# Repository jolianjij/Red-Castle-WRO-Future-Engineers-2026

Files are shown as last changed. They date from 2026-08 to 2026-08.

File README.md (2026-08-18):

<p align="center">
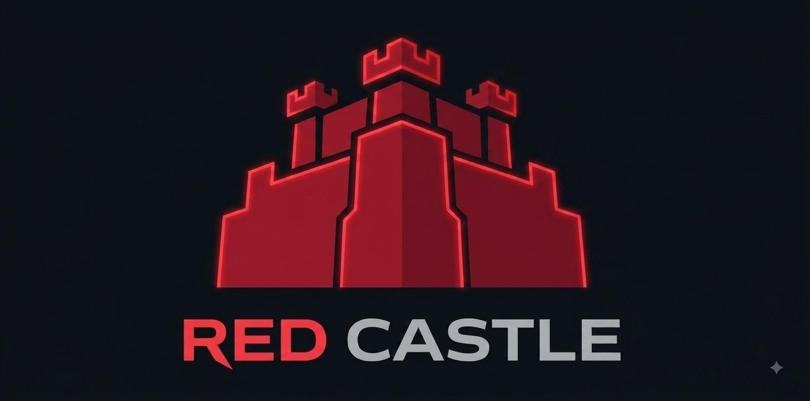
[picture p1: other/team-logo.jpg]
Team The Red Castle
  
</p>

<h1 align="center">Team The Red Castle — WRO 2026 Future Engineers</h1>

An autonomous, self-driving model car for the **World Robot Olympiad 2026,
Future Engineers** category. The mission is the **Open Challenge** (three laps of
a track with a randomised wall layout) and the **Obstacle Challenge** (three laps
avoiding red and green traffic signs, then parking in a marked bay), driven by a
**single camera as its only sensor** — no LiDAR, no ultrasonic rangefinders, no
wheel encoders, no IMU. The Open Challenge runs the full mission; the Obstacle
Challenge currently completes the driving and sign-passing portion, with the
parking manoeuvre still being wired in — see [§10](#10-results--future-work).

> **Design thesis:** everything the car needs to know — where the walls are, which
> way to lap, where the traffic signs are, and where the parking lot is — is
> visible. A well-tuned camera plus disciplined image processing can do the whole
> job, so we spent our engineering effort on making that one sensor reliable
> rather than fusing many.

---

## Table of contents
1. [The challenge](#1-the-challenge)
2. [Vehicle at a glance](#2-vehicle-at-a-glance)
3. [Mobility management](#3-mobility-management)
4. [Power & sense management](#4-power--sense-management)
5. [Software & obstacle management](#5-software--obstacle-management)
   · [flowchart](#51b-control-loop-flowchart) · [direction & laps](#51b-2-direction-and-lap-counting)
   · [obstacle priority](#51c-obstacle-challenge-priority)
   · [subsystem map](#56-how-the-subsystems-fit-together)
   · [testing & metrics](#57-testing-tuning-and-validation)
   · [risks](#58-risks-and-mitigations)
6. [Calibration workflow](#6-calibration-workflow)
7. [Build & run](#7-build--run)
8. [Bill of materials & cost](#8-bill-of-materials--cost)
9. [Engineering process](#9-engineering-process)
10. [Results & future work](#10-results--future-work)
11. [Repository map](#11-repository-map)
12. [Team](#12-team)

---

## 1. The challenge

WRO Future Engineers asks for a fully autonomous vehicle that drives a track
bounded by walls:

- **Open Challenge** — 3 laps; the inner walls are placed at random distances each
  round, so the path width changes and cannot be hard-coded.
- **Obstacle Challenge** — 3 laps with red/green **traffic signs** on the track:
  the car must pass **red signs on their right** and **green signs on their left**,
  then finish by **parking** in the magenta parking lot.

Scoring rewards completing laps without touching walls or signs, correct sign
handling, a clean park, and — importantly — **thorough engineering documentation**
(this repository).

## 2. Vehicle at a glance

| Subsystem | Choice |
|---|---|
| **Compute** | Raspberry Pi 4 Model B, **2 GB RAM** (Raspberry Pi OS *Bookworm*, 64-bit) |
| **Sensor** | **OV5647 Wide-angle** camera (5 MP, ~120° FOV, **fixed focus**) — sole sensor |
| **Steering** | **Ackermann** front steering, MG90S servo on **GPIO13**, **±35° max** |
| **Drive** | **N20 gear motor** (12 V, 200 rpm) → **25:20 gear pair** → **differential** on the rear axle |
| **Driver** | **L9110S** H-bridge on **GPIO24 / GPIO23** |
| **Control** | One push button on **GPIO19** — press to start, press again to stop |
| **Power** | 3 × 18650 (series) → motor driver directly; separate buck converter → Pi; common ground |
| **Chassis** | 3D printed in **PLA+ Silk Silver** on a **Bambu Lab A1**, designed in **Fusion 360** |
| **Software** | Python 3, OpenCV, Picamera2 |

_Vehicle photos: [`v-photos/`](v-photos) · driving video: [`video/video.md`](video/video.md)_

### Specifications

| Property | Value |
|---|---|
| Drive motor | N20 gear motor, 12 V, 200 rpm |
| Transmission | 25:20 spur pair (1.25:1) → differential, rear axle |
| Steering | Ackermann, ±35° max |
| Camera height / tilt | 12.5 cm above the mat / ~15° down |
| Mass | **407 g** |
| Theoretical top speed | **≈ 0.39 m/s** (39 cm/s), no-load — see §3.4 |
| Wheel diameter | **4.7 cm** |
| Wheelbase (front axle ↔ rear axle) | **9.4 cm** |
| Track (rear wheel centre ↔ centre) | **8.5 cm** |
| Overall dimensions (L × W × H) | **14.2 × 9.3 × 15 cm** |
| Print material | PLA+ Silk Silver |
| Printer / CAD | Bambu Lab A1 / Fusion 360 |

## 3. Mobility management

### 3.1 Chassis
A custom chassis designed in **Fusion 360** and 3D printed in **PLA+ Silk Silver**
on a **Bambu Lab A1** (source CAD, STLs and sliced plates in [`models/`](models)).
It carries the Pi, battery, motor driver, drive motor, steering servo and the
camera mast. Design priorities: low and central mass, a rigid camera mast, and
easy access to the wiring.

<p align="center">
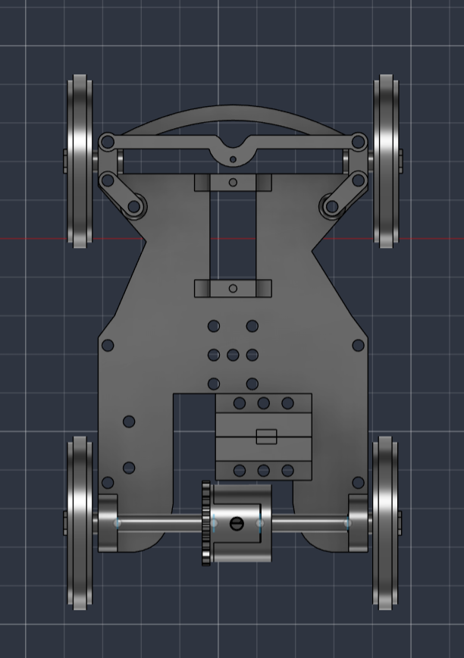
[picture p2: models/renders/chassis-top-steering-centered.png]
Chassis, steering centred
  
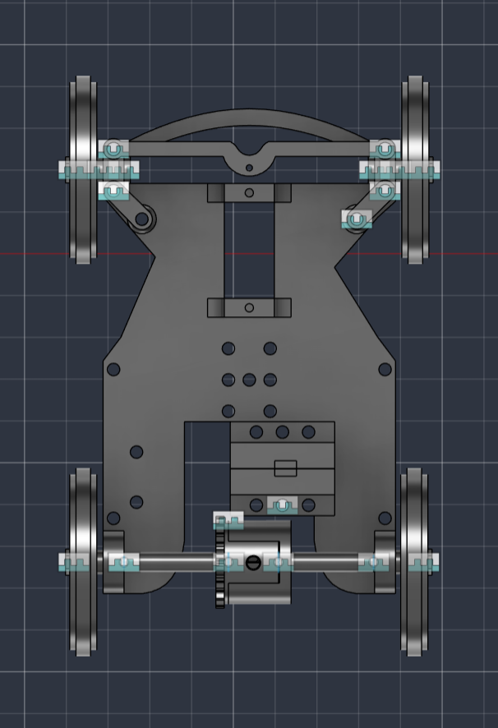
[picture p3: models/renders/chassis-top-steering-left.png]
Chassis, steering turned
  
</p>

### 3.2 Steering — Ackermann
Front-wheel **Ackermann steering** driven by a single MG90S servo (GPIO13, a
hardware-PWM pin for a smooth, low-jitter signal). Metal gears over the plain
SG90 hold up better to the full-lock steering the scripted turns and wall-
emergency escapes both drive it to repeatedly. The servo drives a central
bell-crank and tie-rod to both steering knuckles, so the **inner wheel turns more
sharply than the outer one** through a corner — each wheel follows its own turning
radius instead of fighting the other.

**Maximum steering angle: ±35°**, the mechanical limit of the linkage. `STEER_MAX`
in [`src/config.py`](src/config.py) caps *every* steering command — wall-following,
obstacle-passing and emergency turns — from one constant.

### 3.3 Drivetrain — differential
An **N20 gear motor (12 V, 200 rpm)** drives the rear axle through a **25:20 gear
pair (1.25:1 reduction)** into a **differential**.

> **Engineering decision — why a differential mattered.** Our first drivetrain
> used a *solid* rear axle, forcing both driven wheels to the same speed. In a
> corner the outer wheel must travel further than the inner one, so with a solid
> axle they *scrub* — losing traction, pushing the car wide, and sometimes
> stalling it mid-turn. We worked around it by cutting the steering limit down to
> roughly **8°**, which kept traction but left the car unable to corner properly.
> Fitting a **differential** removed the constraint at its source: the wheels can
> now rotate at different speeds, so we run the **full ±35°** of the linkage and
> corner tightly without scrub. See [`Documentation.pdf`](Documentation.pdf) §5.

The motor is driven by an **L9110S** dual H-bridge:

| L9110S | Connection |
|---|---|
| `A-IA` | GPIO24 — PWM here = **forward** |
| `A-IB` | GPIO23 — PWM here = **reverse** |
| `VCC` | Battery + (motor supply) |
| `GND` | Common ground |
| MOTOR-A | Drive motor |

Speed = PWM duty on one input, the other held LOW. The L9110S was chosen for its
tiny size and simple two-pin-per-motor interface.

> **Safety rule in software.** `motor()` **never switches forward↔reverse
> directly**: it first coasts to a stop and waits (`STOP_FLIP_DELAY`) before
> driving the other way. A hard reversal while the motor is still spinning dumps
> the motor's back-EMF onto the supply and can destroy the Pi's regulator — we
> learned this the hard way (see the journal).

### 3.4 Torque and speed reasoning

The drivetrain was sized around one question: **how fast can the car go while the
vision loop still has time to react?**

**Speed chain**

```
N20 motor          200 rpm  @ 12 V (no load)
  ↓ 25:20 spur pair (1.25:1 reduction)
Differential axle  200 / 1.25 = 160 rpm
  ↓ wheel circumference
Ground speed       v = π · D · 160 / 60   (D = wheel diameter in m)
```

With our **measured wheel diameter (4.7 cm)**:

```
v = π × 0.047 m × 160 rpm / 60 = 0.394 m/s  ≈ 39 cm/s  (no-load ceiling)
```

That is the motor's theoretical maximum with nothing slowing it down. The real
running speed is lower once tyre friction, the differential, and the car's 407 g
mass are accounted for — the 100% cruise setting in software is what actually
runs during a lap, with `cruise_speed()` easing it back further under steering.

**Why gear down at all?** The 1.25:1 reduction trades ~20 % of top speed for
~25 % more torque at the axle (torque scales with the reduction, speed inversely).
That matters because:

- The car must **pull away from rest** repeatedly and climb over the mat seam
  without stalling. Our earlier drivetrain *did* stall — see the journal.
- The L9110S wastes ~1.5–1.8 V, so the motor never sees the full pack voltage;
  extra mechanical advantage compensates for the lost electrical headroom.
- More torque means the controller can use **lower duty cycles** for the same
  motion, which keeps current (and driver heating) down.

**Why not faster?** The vision loop runs at a finite frame rate. At ~0.5 m/s the
car covers ~2–3 cm per frame, so a wall or sign is seen many frames before it
matters. Doubling the speed would halve that reaction margin without improving the
score — the challenge rewards *completing* laps cleanly, not raw speed. The
software also **reduces speed in proportion to steering effort**
(`cruise_speed()`), so the car is fastest exactly where it is safest: on straights.

**Mechanical stability.** At **407 g** total mass on a **14.2 × 9.3 × 15 cm**
footprint, the car is light and compact enough that keeping mass low and central
matters for cornering grip — the battery and Pi sit over the **9.4 cm wheelbase**,
between the front and rear axles, rather than overhanging either end. The **8.5 cm**
rear track keeps the wheelbase-to-track ratio close to 1:1, which is a stable
proportion for cornering without tipping risk. The camera sits on a rigid mast
rather than a flexible arm, and the Ackermann geometry means the wheels roll
rather than scrub through a corner. A vibrating camera would corrupt the wall
measurements, so mast rigidity is a control requirement, not a cosmetic one.

## 4. Power & sense management

### 4.1 Power topology
Early on, the Pi rebooted every time the motor drew current. The fix defines our
power design and is now standard on the car:

```
3 x 18650 (series) ─┬──────────────────────► L9110S VCC   (motor power, direct)
   via rocker switch└─► DC-DC buck (5 V) ───► Raspberry Pi 5V
Battery − ──── common ground ── L9110S GND ── Pi GND
```

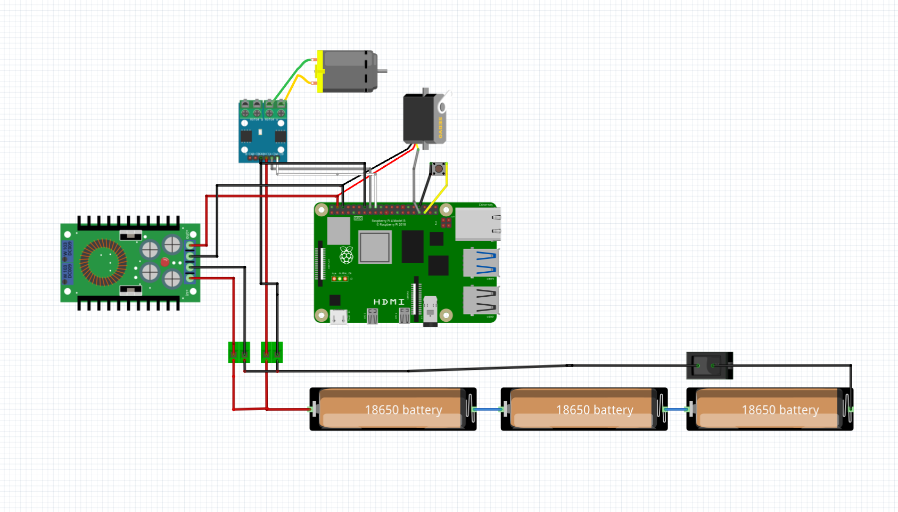
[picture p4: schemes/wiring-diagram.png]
Wiring diagram


_Full wiring notes: [`schemes/`](schemes)._

1. **Separate rails** — the motor draws straight from the battery; the Pi has its
   **own regulator**. Motor current spikes never pass through the Pi's supply.
2. **Common ground** — Pi, driver and battery negatives are tied together so the
   GPIO control signals share a reference. (Without it, the only link between Pi
   and driver is the signal wire, and motor return current back-feeds the GPIO pin
   — which browns out or damages the Pi.)

### 4.2 Power budget

Sizing the pack: what draws current, how much, and for how long.

| Load | Rail | Typical | Peak | Notes |
|---|---|---|---|---|
| Raspberry Pi 4 (2 GB) | 5 V (buck) | ~0.6 A | ~1.2 A | rises while the vision loop runs |
| OV5647 camera | 3.3 V via CSI | ~0.25 A | ~0.25 A | powered by the Pi, no separate rail |
| MG90S steering servo | 5 V (buck) | ~0.15 A | ~0.7 A | peak only during a fast steering step |
| N20 drive motor | 12 V (battery) | ~0.15 A | ~0.8 A | limited by the L9110S's ~0.8 A ceiling |
| L9110S quiescent | 12 V | ~0.01 A | — | negligible |

**Reasoning**

- **Pi rail:** 0.6 + 0.25 + 0.15 ≈ **1.0 A typical**, ~2.1 A worst case if the Pi
  peaks while the servo slams. The buck converter is specified at **≥ 3 A**, giving
  roughly 40 % headroom over the worst case — deliberately generous, because
  under-sizing this rail is what caused our early brownouts.
- **Motor rail:** the motor is fed **straight from the pack**, so its spikes never
  touch the Pi's rail. This separation is the single most important power decision
  on the car (§4.1).
- **Runtime:** 3 × 18650 in series keeps the *capacity* of one cell (~2500–3000 mAh)
  while tripling voltage. The 12 V side draws ~0.15 A average; the 5 V side draws
  ~1.0 A but the buck converter steps *down*, so the current it pulls from the 11 V
  pack is roughly `1.0 A × 5 V / 11 V / 0.85 ≈ 0.53 A`. Total ≈ **0.7 A**, giving on
  the order of **3–4 hours** of running — far beyond the few minutes a run needs.
  Practice sessions, not runtime, drain the pack.
- **Failure points considered:** motor stall (bounded by the L9110S current limit),
  reverse back-EMF (handled in software by a forced coast before any direction
  change), pack sag under load (why the rails are separated), and the fact that a
  freshly charged 12.6 V pack sits marginally above the L9110S's 12 V rating — a
  known watch-item logged in [`schemes/`](schemes).

_These are datasheet/typical figures used for sizing; a clamp-meter measurement of
the real draw is a pending task._

### 4.3 Sensing — the camera
The camera is the entire perception system, so most of our tuning went here.

**Sensor choice.** We began with a Raspberry Pi Camera Module 3 Wide (IMX708) but
switched to an **OV5647 wide-angle module**. The Module 3's large sensor and
autofocus lens gave a *shallow depth of field*: focus it on the mat and distant
traffic signs blurred, which desaturated their colour and made them undetectable.
The OV5647 is a **small-sensor, fixed-focus** module, so its depth of field covers
the whole track — near mat and far walls are sharp simultaneously — and there is
no autofocus to hunt mid-run. Losing autofocus cost us nothing; a ground robot
never needs to refocus.

**Connection.** The camera uses the Pi's dedicated **CSI port** via a flat ribbon
cable — it takes no GPIO pin and needs no separate power, which is why it does not
appear on the wiring diagram.

**Mount — justified by field geometry.** **12.5 cm above the mat**, tilted **~15°
downward**, centred laterally and facing straight ahead on a rigid mast. It is
physically mounted **upside-down**, so frames are rotated 180° in software.

Each number follows from the field itself:

| Choice | Driven by | Reasoning |
|---|---|---|
| **Height 12.5 cm** | walls are **10 cm** tall | The lens must sit **above the wall line** so the camera looks *down onto* the mat and sees the wall **base** — the white-mat/black-wall edge, the highest-contrast feature available. Below 10 cm the walls would fill the frame as a flat black band with no distance information. |
| **Not much higher** | depth resolution vs clutter | Raising the camera improves distance precision by only ~30 % at long range while showing more of the room *over* the walls. Not worth the extra clutter and mast flex — analysed in the journal. |
| **Tilt ~15° down** | track width & look-ahead | Enough downward angle to keep the mat and both wall bases in the lower frame, while still seeing far enough ahead to detect a corner and a traffic sign before reaching them. |
| **Centred, zero yaw** | left/right symmetry | Wall following compares the **left half against the right half** of the image. Any lateral offset or twist becomes a permanent steering bias that no amount of tuning removes. |
| **120° wide lens** | corridor width | A narrow lens cannot see **both** side walls at once in the corridor; the wide lens keeps both walls and the corner lines in a single frame. |
| **Rigid mast** | measurement noise | Vibration blurs the wall edge and injects noise straight into the steering loop, so mast stiffness is a control requirement, not cosmetic. |

**Calibration method.** Colour thresholds are field-calibrated, never hard-coded:
`tools/camera_tune.py` first fixes the *image* (exposure, gain, white balance,
saturation) and writes `camera_settings.json`; `tools/color_tuner.py` then samples
each real object on the real mat and writes `colors.json`. Steering centre is
calibrated by `tools/servo_center.py` into `servo_center.txt`. The car reads all
three files at start-up, so re-calibrating never means editing code.

**Locked settings** (`src/camera.py`), chosen from on-field capture tests:

| Setting | Value | Why |
|---|---|---|
| Sensor mode | 1296×972 (full ~120° FOV) → scaled to 640×480 | keep the wide FOV; cropped modes would lose it |
| Orientation | `hflip + vflip` (180°) | camera mounted upside-down |
| Focus | **fixed** (no AF hardware) | deep depth of field — sharp from the near mat to the far wall |
| Exposure | fixed (~9–12 ms) | freeze motion — auto-exposure ran ~60 ms and smeared when moving |
| White balance | locked `ColourGains` | keep HSV thresholds stable as the car turns toward/away from lights |
| Saturation | raised (~1.4) | separates red / orange / green / magenta in HSV, free in the ISP |

> **Why camera-only?** A single well-configured camera sees walls, the orange/blue
> corner lines, the coloured signs and the parking lot — everything the rules
> reference. Removing LiDAR/ultrasonic cut cost, weight, wiring and failure modes,
> and let us focus on making the vision robust (locked exposure/AWB, fixed focus,
> field-tuned HSV).

## 5. Software & obstacle management

All control software is in [`src/`](src). Four core modules import each other and
run together; the calibration and test utilities live in [`src/tools/`](src/tools).

```
src/robot.py               shared library — pins, servo()/motor(), HSV masks, wall/line/pillar analysis
src/camera.py              locked camera setup
src/open_challenge.py      Open Challenge main
src/obstacle_challenge.py  Obstacle Challenge main
```

### 5.1 Vision pipeline
`capture → 180° flip → crop the mat ROI → resize 320×160 → median blur → HSV`.
HSV is computed with `cv2.COLOR_BGR2HSV` everywhere so thresholds transfer between
the tuner and the challenge code. Six colours are thresholded from `colors.json`
(produced by `tools/color_tuner.py`, values shown are our measured ranges):

| Colour | Used for | HSV range (H, S, V) |
|---|---|---|
| black | walls | a **two-tier** test, not a single threshold — see below |
| blue | corner line (CCW) | H 96–135, S 60–255, V 70–200 |
| orange | corner line (CW) | H 2–13, S 72–170, V 70–255 |
| green | traffic sign | H 30–95, S 140–255, V 30–170 |
| red | traffic sign | H 170–5 (wraps), S 150–255, V 60–255 |
| magenta | parking lot | H 130–145, S 177–255, V 93–255 |

**Wall detection is a two-tier test, not a brightness threshold.** A single
"value < 62" test also lit up the blue/orange lines and the mat's printed dotted
markings, because they're dark too — and unevenly between the two frame halves,
which injected a steering bias. A real wall is either **very dark** (V < 32,
regardless of saturation) **or dark and desaturated** (V < 62 **and** S < 90).
The two-case test matters because HSV saturation is numerically unstable at very
low brightness — a black wall can report S > 200 from sensor noise, so testing
saturation alone throws real walls away. The magenta parking-lot pixels are also
counted as wall until the parking phase, since we have no parking-specific
calibration yet.

**Where colours are searched matters as much as their range.** Corner lines are
painted on the mat, so they can only appear in the image's lower portion —
searching the *whole* frame let bluish wall/background pixels near the top
trigger a false blue-line reading on ~40% of frames in one test run. Line search
is now restricted to the bottom 45% of the region of interest.

### 5.1b Control-loop flowchart

Every frame runs the same **look → think → act** loop. Each challenge program
owns its own `decide()` — one pure function holding the whole priority ladder,
with no hardware or camera in it, so the entire brain can be unit-tested on a
laptop (`tools/test_logic.py`).

```mermaid
flowchart TD
    A([Start]) --> B[Capture frame<br/>OV5647, 180 deg flip]
    B --> C[Crop mat ROI, resize 320x160,<br/>median blur, convert to HSV]
    C --> D[Measure left/right wall density,<br/>front density, line fractions]
    D --> E[LapTracker.update:<br/>direction + lap counting]
    E --> F{Either wall past<br/>WALL_EMERGENCY?}
    F -- yes --> G[Proportional escape,<br/>full lock if BOTH walls close]
    F -- no --> H{Scripted turn<br/>active?}
    H -- yes --> I[Hold full lock in the<br/>locked direction]
    H -- no --> J{Front wall very close<br/>and direction known?}
    J -- yes --> K[Trigger the turn anyway<br/>-- geometry backup]
    J -- no --> L[Outer-wall PD control:<br/>hold target distance to ONE wall]
    G --> M[Clamp to STEER_MAX, set servo]
    I --> M
    K --> M
    L --> M
    M --> N[Scale speed down with<br/>steering effort, set motor]
    N --> O[Log the frame to CSV]
    O --> P{Lap count satisfied<br/>and timer expired?}
    P -- no --> B
    P -- yes --> Q([Stop: motor 0, servo centre])
```

### 5.1b-2 Direction and lap counting

Direction is decided **once**, from the corner lines, and is never re-decided —
that is what stops the car flipping from clockwise to counter-clockwise mid-run.

- **The first time a corner line is seen**, whichever colour has the larger pixel
  count in that frame sets the direction: orange bigger → clockwise, blue bigger
  → counter-clockwise. From that point `direction` is fixed for the whole run.
- **Wall geometry is a second opinion, not a vote.** At the same moment, if the
  two frame halves differ by at least `GEOM_DIR_MIN_DIFF` (0.08), we check
  whether geometry agrees. If it does, the log records a confirmation; if not, a
  disagreement is logged but the line's decision stands. This threshold exists
  because, measured head-on to a corner, the two halves read 0.26 vs 0.22 — a
  0.04 difference that is noise, not information, and it once produced a
  confident but wrong guess against a correct line reading.
- **Lap counting only runs once direction is known**, and only from a **line
  crossing**: a colour going from present to absent (a falling edge) counts one
  *quadrant* — but only if the line lockout timer has expired. That timer
  restarts on every count, so one physical crossing is read exactly once even if
  the mask flickers.
- **What this means honestly:** if the corner lines are never detected for an
  entire run, direction never locks and laps never count — wall-following still
  works (it defaults to the clockwise convention), but the run won't finish
  itself. `FORCE_DIRECTION` in `config.py` is the manual override for this case:
  set it before a run if lighting or colour tuning is in doubt.
- **Front-wall geometry has one job at this level**: if the car is already
  driving in a known direction and a wall gets very close ahead
  (`FRONT_TURN_BACKUP`) without a scripted turn already running, it triggers the
  turn anyway so a missed line can't drive the car into the wall. This backup
  protects the car, not the lap count — it does not add a quadrant.

Every run's log ends with a summary line, e.g. `direction=CCW via bigger line
(blue 0.061) | corners=11 (geom 0, line 11) | disagreements=0`, so a run can be
read back and checked without re-watching it.

### 5.1c Obstacle Challenge priority

Steering is decided by a strict **priority ladder** in one pure function,
`decide()`. Exactly one branch answers each frame, ordered so a lower-priority
behaviour can never override a safety-critical one.

```mermaid
flowchart TD
    A[Every frame] --> P{Still in the<br/>parking lot?}
    P -- yes --> P1[Measure magenta each side,<br/>drive out, LOCK the direction]
    P -- no --> K{Corner just counted, and the<br/>last sign pushed us inward?}
    K -- yes --> K1[Fixed 30 deg kick<br/>out of the corner]
    K -- no --> W{Wall past<br/>WALL_EMERGENCY?}
    K1 --> W
    W -- yes --> W1[Ramped escape,<br/>floored by the controller]
    W -- no --> S{Sign visible?}
    S -- yes --> S1[Place it: red to our right,<br/>green to our left]
    S -- no, seen in the last 3 s --> H[Hold, then run straight]
    S -- no --> L[Outer-wall PD lane keeping]
```

| # | Behaviour | Why it sits at this level |
|---|---|---|
| **0** | **Parking exit** | Runs once, before the car moves. Inside the lot the magenta walls are close *on purpose*, so it must outrank the wall escape or the escape would fight the way out. |
| **1** | **Corner kick** | A committed open-loop manoeuvre. It outranks the wall escape because it is *deliberately* turning toward a wall — except when a wall closes from the **opposite** side, which cancels it. |
| **2** | **Wall escape** | Touching a wall ends the run. Ramps 50 %→100 % across the danger band and is **floored by the normal controller**, because an escape weaker than the controller it replaces steers *into* the wall (measured: −0.8° produced where the follower wanted −17°). |
| **3** | **Sign steering** | Passing signs correctly scores points, so it outranks plain lane keeping. |
| **4** | **Sign hold** | Detection flickers frame to frame (measured: one sign's area went 61 → 851 → 0 → 1060 over four frames). The hold is in **seconds**, not frames, so it does not change with frame rate. |
| **5** | **Lane keeping** | The same outer-wall PD proven in the Open Challenge, used when nothing else applies. |

**Why lane keeping exists at all.** A design that steers only toward signs and
relies on the wall override firing "often enough" between them does not hold on
our optics: measured mid-corridor readings of 0.112/0.129 against a 0.213
override threshold, meaning the car would drive dead straight for 44 % of a test
run with nothing correcting it. Falling back to the proven outer-wall controller
closes that gap.

### 5.1d Leaving the parking lot — and how it fixes the direction

The car starts inside the magenta parking lot. Whichever side is more blocked is
the side it *cannot* leave by, so the free side is both the way out **and** the
direction the lap will run. One measurement, taken before the car has moved,
answers both questions:

| what the camera sees | way out | lap direction |
|---|---|---|
| more magenta on the **left** | leave **right** | **CW** (+1) |
| more magenta on the **right** | leave **left** | **CCW** (−1) |

Because `+1` already means "steer right" everywhere in the code, the exit
steering is simply `direction × angle` — one number answers both.

The measurement is averaged over 8 frames while the car is **stationary**: the
only moment in the run with no motion blur, and worth spending. If neither side
shows enough magenta the car declines to guess and leaves the direction to the
corner lines, because a wrong direction locked at frame one would ruin the whole
run.

> **We do not add the black wall to this measurement.** A synthetic test first
> suggested the two signals were anti-correlated — the magenta wall occludes the
> black wall behind it. **Measured on the real track they agree**: in the lot,
> magenta read L 0.716 / R 0.449 while the wall read L 0.174 / R 0.093, both
> naming the same side. The anti-correlation was an artifact of the test image,
> where blank background counted as wall.
>
> It stays off for a simpler reason: magenta alone already gives a clear margin,
> and it is the *direct* signal — the parking lot is defined by magenta, whereas
> black is every wall on the track. `PARK_USE_WALL` enables it if a venue ever
> makes magenta's margin marginal.

### 5.2 Open Challenge algorithm

1. **Direction** is set once, from the first corner line seen (§5.1b-2), and
   never changes for the rest of the run.
2. **Between corners**, a PD controller holds a fixed distance to the **outer**
   wall only — the left wall clockwise, the right wall counter-clockwise. The
   *inner* wall is never referenced, because its distance from the track centre
   is randomised each round; the outer wall is the one constant.
3. **At a corner**, crossing the driving-direction's line fires a **scripted
   turn**: full steering lock in the known direction, held for at least 0.35 s
   and at most 1.1 s, ending as soon as the way ahead reads clear rather than on
   a fixed clock. A fixed-duration turn was tried first and over-rotated into the
   inner wall in both directions (measured: inner-wall density climbed
   0.126 → 0.195 → 0.278 during one such turn) — ending on "the corner is
   clear" instead of "a timer expired" fixed that.
4. **A wall emergency always wins**, in any state: if either wall crosses
   `WALL_EMERGENCY`, the controller escapes proportionally to how close it is,
   and if *both* walls are close at once (jammed facing a corner) it latches a
   single escape direction instead of alternating between the two — an earlier
   version let left and right readings cross each other frame to frame, which
   flipped the command between +20° and −20° and made the car directionless
   exactly when it needed decisive action.
5. **Stop** once 11 quadrants are counted *and* the lap timer has expired, so the
   car finishes driving through the last straight instead of halting on the line.

### 5.3 Obstacle Challenge algorithm

1. **If a sign is visible**, steer to place it on the correct side: the target
   column is computed from the sign's position and how close it is, sliding
   further toward the frame edge as the sign nears, so the car curves around it
   rather than swerving late.
2. **If a sign was visible recently but isn't this frame**, hold the last
   command for a few frames instead of reacting to the drop-out — this is what
   keeps a single flickered detection from aborting a pass halfway through.
3. **If no sign is in view or remembered**, fall back to the same outer-wall
   lane-keeping law as the Open Challenge, so the car doesn't simply coast
   straight between signs.
4. **A wall override sits above all three** — the same emergency threshold as
   the Open Challenge, and it also does the job of turning the car through each
   corner, since the Obstacle Challenge has no separate scripted-turn sequencer.

### 5.4 Speed
Base speed is `CRUISE`; `cruise_speed()` **eases off in proportion to steering
effort**, so the car runs fast on straights and slows automatically for corners.

## 5.6 How the subsystems fit together

```mermaid
flowchart LR
    subgraph POWER[Power]
        BAT[3 x 18650<br/>~11.1 V] --> SW[Switch]
        SW --> BUCK[Buck 5 V]
        SW --> DRV[L9110S]
    end
    subgraph SENSE[Sensing]
        CAM[OV5647 wide<br/>fixed focus] -- CSI --> PI
    end
    subgraph THINK[Compute]
        PI[Raspberry Pi 4<br/>robot.py loop]
    end
    subgraph ACT[Actuation]
        SRV[MG90S servo<br/>Ackermann]
        MOT[N20 motor] --> GEAR[25:20] --> DIFF[Differential] --> WHL[Rear wheels]
    end
    BUCK --> PI
    BUCK --> SRV
    DRV --> MOT
    PI -- GPIO13 PWM --> SRV
    PI -- GPIO24/23 PWM --> DRV
    CFG[(colors.json<br/>servo_center.txt<br/>camera_settings.json)] --> PI
    PI --> LOG[(CSV run log)]
```

**Interactions that actually constrained the design**

| Interaction | Constraint it created |
|---|---|
| Motor ↔ Pi share one battery | Rails **must** be separated and grounds tied, or the Pi browns out (§4.1). |
| Drivetrain ↔ steering software | A solid axle forced the steering limit down to ~8°; the differential raised the mechanical limit to 35°. We run the software limit at **20°** for stability at full speed — mechanics set the ceiling, tuning sets where under it we actually drive. |
| Camera mount ↔ control loop | Mount height/tilt/rigidity determine what the controller can even measure; a loose mast is a control failure. |
| Lighting ↔ colour thresholds | Auto-exposure made HSV drift, so exposure and white balance are **locked** and colours re-tuned on the real mat. |
| Camera choice ↔ obstacle detection | Shallow depth of field blurred distant signs, so the sensor was swapped for a fixed-focus module. |
| Frame rate ↔ top speed | Speed is capped so the car moves only a few cm per frame, preserving reaction margin. |

## 5.7 Testing, tuning and validation

**How we test.** Each subsystem has a dedicated tool so faults are isolated rather
than guessed at (all in [`src/tools/`](src/tools)):

| Stage | Tool | What it proves |
|---|---|---|
| Wiring | `driver_on.py`, `test.py` | servo sweeps, motor turns both ways, camera captures |
| Motor limits | `motor_speed_steps.py` | steps 100 → 50 % to find the stall point |
| Motor path | `motor_debug.py` | separates a PWM fault from a power fault |
| Camera image | `camera_tune.py` | exposure/gain/saturation, with a live `mean_sat / blown% / dark%` read-out |
| Colour | `color_tuner.py` | each colour verified against its real object, mask checked for speckle |
| Wall vs shadow | `shadow_check.py` | splits dark pixels into a "tall solid run" (a real wall) vs a shallow spread (likely shadow), so a misreading can be diagnosed on the spot |
| Outer-wall control | `outer_test.py` | moves the car by hand and prints what the controller *would* steer, before it is ever trusted at speed |
| Decision logic | `test_logic.py` | the whole brain on a laptop, no Pi — 50+ assertions over `decide()`, the lap tracker and the corner kick |
| Full decision chain | `dryrun.py` | runs both challenges' `decide()` against the live camera, **motor never touched** |
| Start/stop button | `button_test.py` | confirms the button's wiring and that one press produces exactly one event |
| Full run | `open_challenge.py` / `obstacle_challenge.py` | logs every frame to `logs/*.csv` |

**Metrics we record.** Every run writes a CSV row per frame — timestamp, cycle,
direction, quadrant, in-corner flag, left/right wall, blue/orange line fractions,
steering and speed — plus a summary line (quadrants, cycles, elapsed time,
ms/cycle). That log is how we tune: after a bad run we read *why* the car did what
it did instead of guessing.

| Metric | Why it matters |
|---|---|
| ms per cycle | loop rate — sets how far the car travels blind between frames |
| quadrants counted vs. real corners | validates lap counting |
| seconds between corners | catches a corner counted twice or missed |
| left/right wall balance on a straight | proves the camera is centred and the controller is not biased |
| steering saturation (% of frames at `STEER_MAX`) | shows whether gains are too high |

**Tuning process.** Change one constant in [`src/config.py`](src/config.py) → run →
read the log → keep or revert. Because every threshold lives in one file and all
calibration lives in JSON/text files, a tuning change never risks breaking code.

## 5.8 Risks and mitigations

| Risk | Impact | Mitigation |
|---|---|---|
| Motor current spike browns out the Pi | run ends, SD card can corrupt | separate rails, own buck converter, common ground (§4.1) |
| Forward↔reverse slam destroys the regulator | hardware loss | `motor()` forces a coast + settle before any direction change |
| Lighting changes at the venue | colour masks fail | exposure/AWB locked; colours re-tuned on site in minutes via `color_tuner.py` |
| Corner line never detected all run | direction never locks, laps never count | **known limitation** — wall-following still runs (default clockwise), but the run won't self-finish; `FORCE_DIRECTION` in config is the manual override if colour is in doubt at the venue |
| One corner line missed mid-run | that quadrant undercounts | the front-wall geometry backup still forces the physical turn, so the car doesn't crash — only the count is affected, not the turn |
| Direction mis-detected | car laps the wrong way | decided once from the larger of the two line readings, cross-checked against wall geometry, then locked for the whole run |
| Camera knocked out of alignment | permanent steering bias | rigid mast; left/right balance check before every run |
| Mat markings or shadows read as a wall | false obstacle / steering bias | two-tier wall test (very dark, or dark **and** desaturated) rejects coloured lines and most shadow; `shadow_check.py` diagnoses any that still gets through — this was a live issue at two corners in field testing and is still being tightened |
| Car stuck against a wall | run wasted | `MAX_CORNER_CYCLES` and `MAX_RUNTIME_S` force an exit/stop |
| Fresh pack exceeds L9110S 12 V rating | driver overheats | monitored; noted in [`schemes/`](schemes) |
| Algorithm underperforms on the day | lost points | every tunable sits in one block at the top of the challenge file — speed, lane distance in cm, sign gains — so behaviour is retuned at the venue without touching logic |
| Car must be stopped mid-run | damage, or a wasted attempt | one button on GPIO19 starts the run and stops it at any moment; the loop polls it every frame |

## 6. Calibration workflow

Every calibration writes a file that `robot.py` loads at start-up, so the
competition code itself never has to be edited to retune the car.

| Tool | Produces | Purpose |
|---|---|---|
| `tools/tune_colors.py` | `camera_settings.json`, `colors.json` | **the venue tool.** Re-locks exposure/white balance, then every colour, then checks all pairs for overlap. Headless — runs over plain SSH. |
| `tools/tune_walls.py --detector` | `wall_settings.json` | what counts as a **wall** in this light |
| `tools/tune_walls.py` | printed constants | density ↔ centimetres, fitted through parked measurements |
| `tools/servo_center.py` | `servo_center.txt` | trim so 0° = straight (current value **−9°**) |
| `tools/button_test.py` | — | confirm the start/stop button's wiring |
| `tools/color_tuner.py` | `colors.json` | the older interactive GUI tuner (needs a screen) |

**The order matters and cannot be swapped**, because each step is measured
through the previous one: **colours → wall detector → distances**. Re-locking
the white balance after tuning colours silently invalidates them; changing the
wall detector changes every density measured against it.

**The wall detector does not use a colour range.** It uses `WALL_V_HARD`,
`WALL_V_SOFT` and `WALL_S_MAX` — three brightness/saturation cuts. Tuning the
`black` colour therefore does *not* retune the walls, which is exactly the sort
of thing that looks like it worked and has not. `tune_walls.py --detector`
samples the wall, the mat and a line and places the thresholds in the gap
between them; if wall and mat overlap in brightness it refuses to write
anything, because no threshold can separate them in that light.

Full competition-day procedure: [`other/venue-setup.md`](other/venue-setup.md).

## 7. Build & run

**Raspberry Pi OS Bookworm** — Picamera2/OpenCV come from `apt`, **not** pip
(a pip numpy shadows the apt one and breaks Picamera2):

```bash
sudo apt install -y python3-picamera2 python3-libcamera python3-opencv python3-rpi-lgpio python3-venv
```

### Running a challenge

```bash
cd ~/wro2026 && source .venv/bin/activate && python open_challenge.py
```

Then **press the button**. Nothing moves before that — the program arms and
waits. Pressing it again stops the run at any moment; it is also the emergency
stop, and the loop polls it every frame.

### At the start line, with no laptop

```bash
./autostart.sh on
```

The program then launches at every power-on, so the start-line procedure becomes
**power the car, press the button**. This is safe precisely *because* the
program waits for the button: booting into it only arms the car. When a run
finishes the service restarts it, re-arming it for the next press. Which program
runs is one line at the top of `run.sh`.

### Before every deploy

```bash
python tools/test_logic.py    # the whole brain, on a laptop, no Pi needed
python tools/dryrun.py        # both challenges, live camera, motor untouched
```

## 8. Bill of materials & cost

Full component list: [`other/bill-of-materials.md`](other/bill-of-materials.md).
Wiring: [`schemes/`](schemes). **Total build cost: ≈ $120** (electronics, printed
parts, fasteners and battery combined).

## 9. Engineering process

The interesting part of this project was making one camera and a cheap drivetrain
reliable. The full design log — sensor choice, the power-brownout debugging, the
motor stall, the no-differential steering decision, and the camera focus/exposure
tuning — is in the Evolution section of **[`Documentation.pdf`](Documentation.pdf)**.

## 10. Results & future work

**Open Challenge — complete.** The vehicle drives the full three laps and stops
correctly **in both directions (clockwise and counter-clockwise)** with stable
control, holding its line along the straights and taking the corners without
contact. Both driving directions are demonstrated in the submitted video.

The decisive fix was not in the controller but in the perception: the wall
detector had been counting the blue and orange corner lines, and the mat's printed
markings, as walls — see [`Documentation.pdf`](Documentation.pdf) §5. Once
corrected, every distance constant was re-measured, so the control setpoints are
now real distances (driving line 40 cm from the outer wall, emergency at 18 cm,
full steering lock at 20 cm of error) rather than tuned pixel fractions.

**Obstacle Challenge — driving and sign-passing complete, parking not yet wired
in.** Sign passing (red on the right, green on the left) and lane keeping between
signs both run, with a short memory that holds a manoeuvre through a flickered
detection instead of aborting it. The magenta parking lot is currently treated
purely as a wall to avoid; detecting the gate and executing the approach is
built into `config.py` as reserved constants but not yet connected into the main
loop. The other known open issue is **shadow at two of the four corners**
occasionally being read as part of the wall, which biases the density measurement
there; `tools/shadow_check.py` was built specifically to separate a genuine wall
(a tall, solid dark run) from a shadow (broad and shallow) and diagnose it in the
field, and the wall test is being tightened against it.

**Future work.**
- Wire the parking manoeuvre into the Obstacle Challenge's main loop.
- Close out the corner-shadow misreading identified above.
- Upgrade wall-following from a pure PD law to a heading + offset controller, so
  the car holds a straighter line rather than correcting after it has already
  drifted.
- Track a sign's position across frames rather than per-frame, to smooth the
  approach further than the current short-memory hold already does.

## 11. Repository map

```
README.md                 # this engineering document
Documentation.pdf          # printable engineering journal (hard-copy submission)
CHECKLIST.md               # submission checklist
src/                       # control software (core + tools/)
models/                    # 3D-printable parts + source CAD
schemes/                   # wiring / electromechanical diagrams
t-photos/                  # team photos
v-photos/                  # vehicle photos (6 angles)
video/                     # link to the driving demonstration
other/                     # BOM, rulebook, misc
```

## 12. Team

<p align="center">
  Red Castle
  &nbsp;&nbsp;&nbsp;
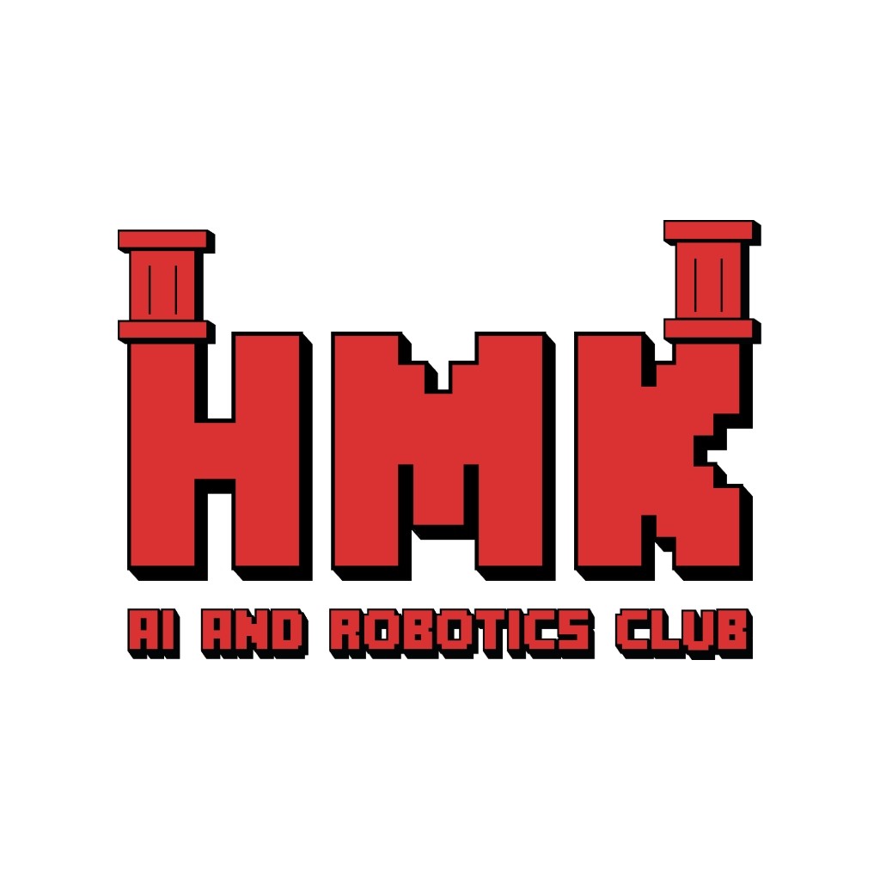
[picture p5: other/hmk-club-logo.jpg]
HMK AI and Robotics Club
  
</p>

**Team The Red Castle** — HMK AI and Robotics Club.

<table>
  <tr>
    <td align="center" width="25%">
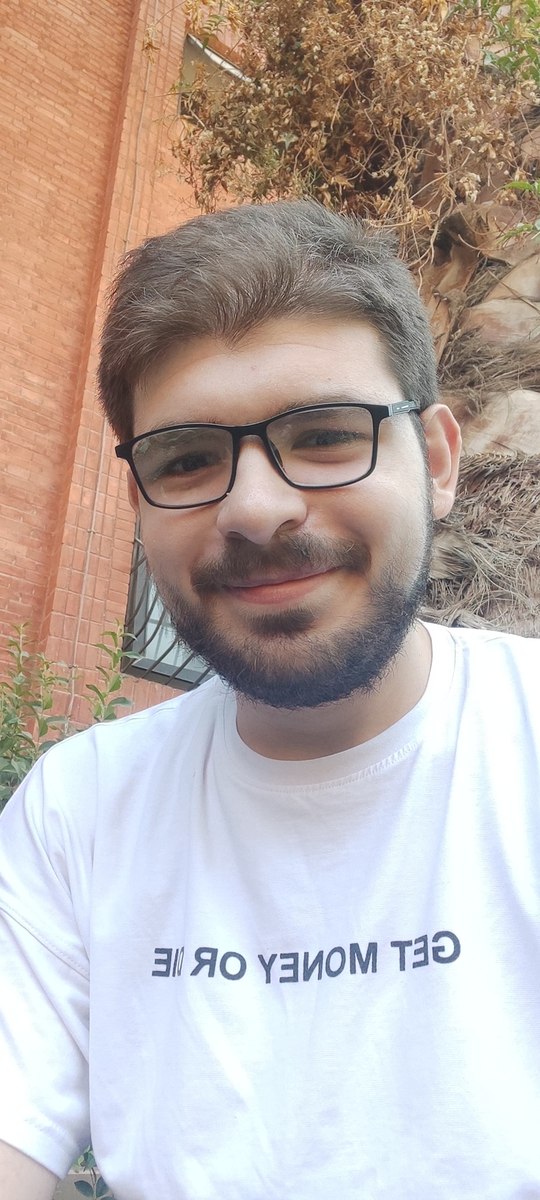
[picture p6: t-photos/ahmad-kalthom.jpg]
Ahmad Kalthom
      <br>
      <b>Ahmad Kalthom</b><br>
      <sub>Coach</sub>
    </td>
    <td align="center" width="25%">
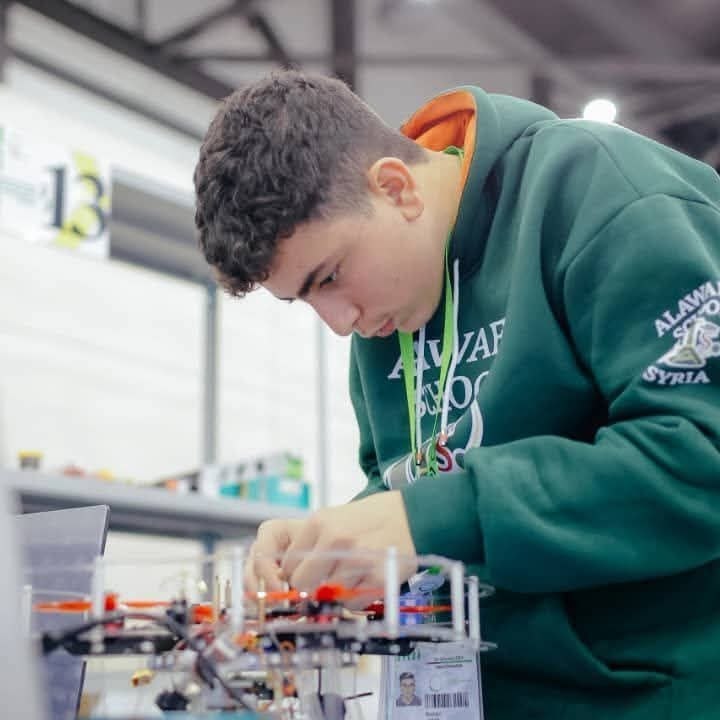
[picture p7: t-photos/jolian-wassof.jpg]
Jolian Wassof
      <br>
      <b>Jolian Wassof</b><br>
      <sub>Team member</sub>
    </td>
    <td align="center" width="25%">
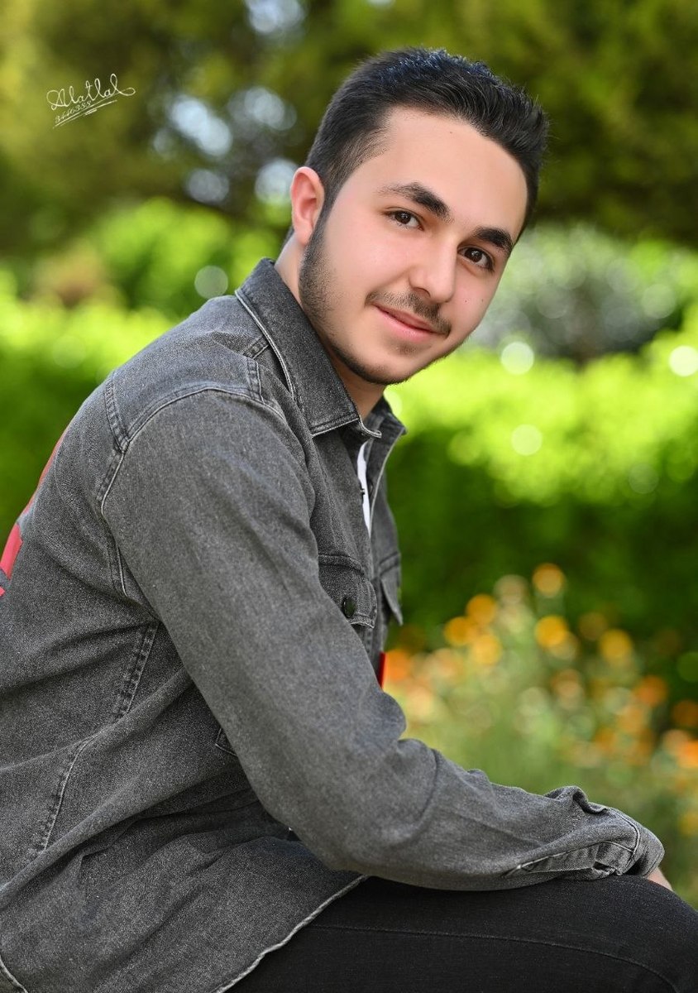
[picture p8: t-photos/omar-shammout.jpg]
Omar Shammout
      <br>
      <b>Omar Shammout</b><br>
      <sub>Team member</sub>
    </td>
    <td align="center" width="25%">
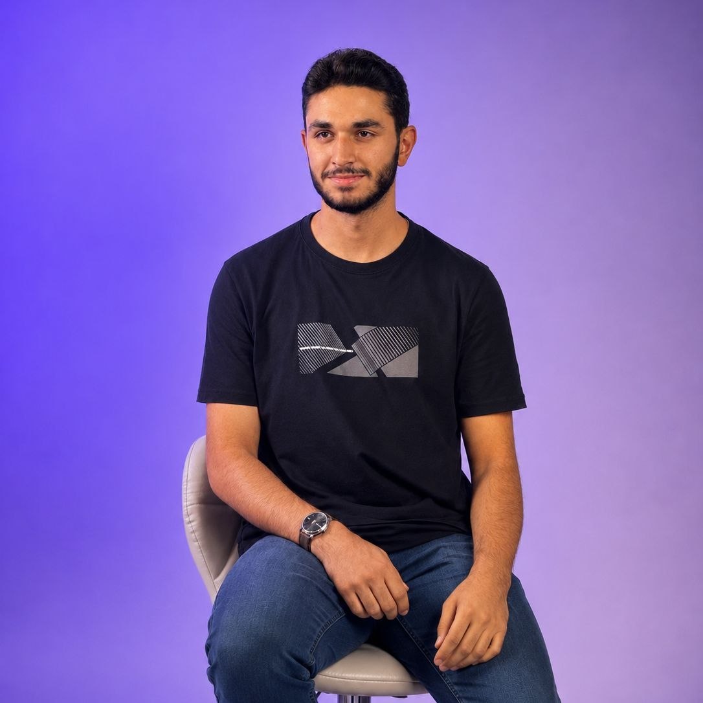
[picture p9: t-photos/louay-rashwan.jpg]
Louay Rashwan
      <br>
      <b>Louay Rashwan</b><br>
      <sub>Team member</sub>
    </td>
  </tr>
</table>

### Ahmad Kalthom — Coach
> Computer and Automation Engineering student at Damascus University, interested
> in embedded systems and automatic control. Works on applied projects to design
> effective automation solutions within a competitive environment.

**Education:** Computer and Automation Engineering, Damascus University
**Focus areas:** Embedded Systems, Automatic Control
📧 ahmedkalthom977@gmail.com

### Jolian Wassof — Team member
> Student at Al-Awael School, interested in artificial intelligence, robotics,
> drones, and engineering. Has competed in the Pacific Olympiad in AI, the Syrian
> Olympiad in AI, and the World Robot Olympiad, as well as mobile robotics and
> unmanned aerial systems competitions. Has built several AI-based robots and
> drones, and conducts research in AI.

**Education:** Al-Awael School
**Focus areas:** Artificial Intelligence, Robotics, Drones
📧 joleanwassof@gmail.com

### Omar Shammout — Team member
> IT Engineering student at Damascus University, interested in robotics,
> artificial intelligence, programming, and electronics. Participates in
> technical activities and projects to develop skills in designing and building
> innovative solutions within a competitive environment.

**Education:** IT Engineering, Damascus University
**Focus areas:** Robotics, Artificial Intelligence, Programming, Electronics
📧 omarhamze.shammout@gmail.com

### Louay Rashwan — Team member
> Computer and Automation Engineering student at Damascus University, interested
> in robotics, artificial intelligence, and electronics. Participates in
> technical activities and projects to develop skills in designing and building
> innovative solutions within a competitive environment.

**Education:** Computer and Automation Engineering, Damascus University
**Focus areas:** Robotics, Artificial Intelligence, Electronics
📧 rashwanlouay@gmail.com

Built on a Raspberry Pi 4 with an OV5647 wide-angle camera.

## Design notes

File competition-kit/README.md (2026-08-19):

# Competition kit — WRO 2026 Future Engineers

Team The Red Castle · HMK AI and Robotics Club

Everything needed at the venue, in one folder. The layout **mirrors the Pi**,
so the whole folder can be copied to `~/wro2026` and every tool will find the
programs next to it.

```
competition-kit/
├── open_challenge.py                  the open challenge program
├── obstacle_challenge.py              the obstacle challenge program
├── WRO2026-Control-and-Tunables.pdf   every tunable + the control equations
├── TUNING-STRATEGY.md                 what to do at the venue, in order
├── build_pdf.py                       regenerates the PDF from the code
└── tools/
    ├── mask_debug.py     every mask on one picture       START HERE
    ├── wall_calib.py     wall-following targets
    ├── line_audit.py     line thresholds
    ├── sign_calib.py     pillar distance and pixel counts
    ├── park_calib.py     parking walls and the exit direction
    ├── color_count.py    pixel count for ANY new colour   surprise challenge
    └── servo_jitter.py   proves whether the servo shake is the pulse
```

## Which program is which

**`open_challenge.py`** — wall following on density, lines only count laps.
Finishes 3 s after the 12th quadrant.

**`obstacle_challenge.py`** — the version you asked for: their original green
release and per-direction line counting, the blocking corner kick on orange,
the `v >= 70` parking-wall filter — **with the parking algorithm removed**.
After the 12th quadrant it finishes like the open challenge instead of hunting
for the parking bay. `PARKING_ENABLED = True` brings the whole thing back.

Both keep every value you tuned on the Pi.

## Running

```bash
cd ~/wro2026 && source .venv/bin/activate && python open_challenge.py
```

Press the button to start. Press it again to stop — it is the emergency stop.

Every run writes its own timestamped CSV under `logs/`, so a bad run is never
overwritten by the next one. Both programs print every tunable at startup, so
the log says what produced it.

## The tools

All of them import the challenge program itself, so they use its real capture,
crop, colour tests and wall mask. They cannot quietly disagree with the car —
which is how two genuine bugs were caught.

| tool | run it when |
|---|---|
| `mask_debug.py` | first thing at the venue, and any time something looks wrong |
| `wall_calib.py cw` / `ccw` | before every session — lighting moves the densities |
| `line_audit.py blue` / `orange` | if a lap is miscounted or a line is missed |
| `sign_calib.py` | if a pillar is ignored or hit |
| `park_calib.py` | before an obstacle run, in the start box |
| `color_count.py` | surprise challenge, or any new colour |
| `servo_jitter.py` | if the steering buzzes |

None of them move the car. The motor is never touched.

## Before the first run of the day

1. `systemctl is-active pigpiod` — must say `active`. Without it the servo
   falls back to software PWM and buzzes. The program warns loudly if so.
2. `python tools/mask_debug.py` — look at the picture.
3. `python tools/wall_calib.py cw` and `ccw` — re-measure the targets.

## Regenerating the PDF

Every number in the PDF is parsed out of the two programs at build time, so it
can never drift from the code. After changing a tunable:

```bash
python build_pdf.py
```

Run it on the laptop — it never imports `picamera2`.

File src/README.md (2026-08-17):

# src — the code

## The whole thing in five files

```
open_challenge.py      RUN THIS   three laps, empty track
obstacle_challenge.py  RUN THIS   three laps, red/green traffic signs
robot.py               the car: hardware, camera, seeing, control
config.py              every tunable number shared by both challenges
camera.py              camera setup (locked exposure and white balance)
```

Only the first two are programs you run. Everything else is support.

```
colors.json            the tuned HSV ranges (made by tools/color_tuner.py)
camera_settings.json   the locked white balance (made by tools/camera_tune.py)
servo_center.txt       steering centre trim (made by tools/servo_center.py)
tools/                 helpers - see below
archive/               superseded experiments, kept for the journal
```

---

## Every challenge program has the same three parts

This is the important bit. Open either program and you will find, in order:

### 1. TUNABLES
A single block at the top. **Nothing outside it needs editing.** Speed,
direction, how far from the wall to drive, how hard to react to a sign.

### 2. `decide()`
The brain. **One frame in, one steering decision out.** It is a *priority
ladder* — a list of `if` statements from most urgent to least, where exactly
one branch answers:

```python
def decide(view, laps, outer, turner):
    if a wall is too close:      return escape        # 1. EMERGENCY
    if we are cornering:         return turn          # 2. TURN
    return follow the outer wall                      # 3. LANE
```

`decide()` touches no hardware and no camera — it is pure arithmetic on
numbers. That is deliberate: it means the whole brain can be tested on a
laptop, with no Pi, in under a second.

### 3. `main()`
The loop. Always the same four steps:

```python
button.wait_for_start()          # nothing moves until you press it
while True:
    view = R.look(cam)           # LOOK   one frame, everything measured
    d = decide(view, ...)        # THINK  one decision
    R.servo(d.steer)             # ACT
    R.motor(speed)
    if button.stop_pressed(): break   # RECORD / FINISH
```

---

## How to write the surprise challenge

The surprise challenge is announced at the venue. You will not have time to
invent anything, so don't — **copy a program and rewrite one function.**

**1. Copy the closest existing program.**
```bash
cp open_challenge.py surprise_challenge.py
```
Start from `open_challenge.py` if the task is about driving and walls; from
`obstacle_challenge.py` if it involves coloured objects.

**2. Change the TUNABLES block** to whatever the new task needs.

**3. Rewrite `decide()`.** This is the only real work. Write the ladder in
plain words first, most urgent at the top, then translate each line:

> *"Don't hit anything. Otherwise, if I can see the thing, go to it.
> Otherwise, keep driving down the middle."*

```python
def decide(view, laps, outer, turner):
    escape = R.wall_emergency(view.left, view.right, outer, laps.direction)
    if escape is not None:
        return Decision(escape, "emergency")
    ...your new rule here...
    return Decision(R.apply_bias(outer.steer(view.left, view.right,
                                             laps.direction)), "lane")
```

**4. Leave `main()` almost alone.** Change the log filename and the printed
header. The button, the loop, the logging and the safety timeout all work
already.

**5. Test before you drive it.**
```bash
python tools/test_logic.py     # on the laptop, no Pi needed
python tools/dryrun.py         # on the Pi, camera on, motor never touched
```

### What you can call inside `decide()`

Everything the car can sense arrives in one `view` object:

| field | meaning |
|---|---|
| `view.left`, `view.right` | how much of that half of the picture is wall. **Bigger = closer.** |
| `view.front` | the same, straight ahead. High means a corner. |
| `view.blue`, `view.orange` | how much corner line is visible |
| `view.hsv` | the raw HSV image, for your own colour work |
| `view.proc` | the colour image, for saving annotated frames |

Useful helpers in `robot.py`:

| call | what it does |
|---|---|
| `R.wall_emergency(left, right, outer, direction)` | escape steering, or `None` if safe |
| `R.mask(hsv, "red")` | pixels matching a tuned colour |
| `R.apply_bias(steer)` | adds the straight-line drift trim (lane keeping only) |
| `R.cruise_speed(base, steer)` | slows down in proportion to steering |
| `R.OuterWallFollower(target=…)` | PD control on the distance to one wall |
| `R.CornerKick(...)` | a fixed, time-boxed, open-loop turn |

**Sign conventions, everywhere:** steering `0` = straight, **+ = right**,
**− = left**. Direction `+1` = clockwise, `−1` = counter-clockwise.

---

## The button (GPIO 19)

One button does both jobs:

- **press once** → the run starts (nothing moves before this)
- **press again** → the run stops, at any time. This is the emergency stop.

Wired between **GPIO19 and GND**, using the Pi's internal pull-up, so no
resistor is needed. Check it before trusting it:

```bash
python tools/button_test.py
```

If it says the button reads PRESSED while you are not touching it, flip
`BUTTON_PULL_UP` in `config.py`. To bench-test without the button at all, set
`BUTTON_REQUIRED = False` and it falls back to pressing Enter.

---

## Tools

| tool | what it is for |
|---|---|
| `test_logic.py` | **run this before every deploy.** The whole brain, tested on a laptop with no Pi. |
| `dryrun.py` | both challenges against the real camera, motor never touched |
| `button_test.py` | check the start/stop button is wired and configured right |
| `color_tuner.py` | tune the HSV ranges → `colors.json` |
| `camera_tune.py` | lock exposure and white balance → `camera_settings.json` |
| `servo_center.py` | find the steering centre → `servo_center.txt` |
| `test.py` | move each piece of hardware on its own |
| `tune_colors.py` | **venue:** re-lock the camera, then re-tune every colour. Headless — works over plain SSH. |
| `tune_walls.py` | **venue:** `--detector` re-derives what counts as a wall in this light; with no flag it calibrates density ↔ centimetres |
| `venue_net.sh` | switch to wired-only; refuses to disable Wi-Fi unless Ethernet is up |

---

## Running on the Pi

```bash
cd ~/wro2026 && source .venv/bin/activate && python open_challenge.py
```

Or use the runner, which picks the program from one line at the top of itself:

```bash
./run.sh
```

`./autostart.sh on` makes that run at every power-on, so at the start line you
only need to power the car and press the button — no laptop and no network.
Full competition-day procedure: [`other/venue-setup.md`](../other/venue-setup.md).

Then press the button. Every run writes a CSV to `logs/`; the obstacle run
also writes `sign_order.txt` and annotated frames to `frames/`.

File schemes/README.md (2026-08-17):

# schemes — electromechanical wiring

Wiring diagram

## Power chain

```
3 × 18650 (series, ~11.1 V nominal) ──► rocker switch ──┬──► L9110S  VCC   (motor power, direct)
                                                        │
                                                        └──► DC-DC buck converter ──► Raspberry Pi 4  5 V
Battery −  ────────── COMMON GROUND ────────── L9110S GND ────────── Pi GND
```

Two rules this diagram exists to enforce:

1. **Separate rails.** The motor is fed **straight from the battery** into the
   L9110S `VCC`. The Pi is fed from its **own step-down converter**. Motor current
   spikes therefore never pass through the Pi's supply. Wiring the motor through
   the Pi's 5 V rail caused repeated brownout reboots early in the build.
2. **One common ground.** Battery −, L9110S `GND` and Pi `GND` are all tied
   together. Without it the only electrical link between Pi and driver is the
   signal wire, and motor return current back-feeds a GPIO pin — the Pi shuts down
   (and the pin can be damaged).

A rocker switch in the battery line is the master on/off.

## Signal connections (authoritative pin map — see [`src/config.py`](../src/config.py))

| Signal | Pi pin (BCM) | Goes to |
|---|---|---|
| Steering servo PWM | **GPIO13** | MG90S servo signal (orange/white) |
| Motor `A-IA` | **GPIO24** | L9110S input — PWM here = **forward** |
| Motor `A-IB` | **GPIO23** | L9110S input — PWM here = **reverse** |
| Start / stop button | **GPIO19** | push button to **GND**. The Pi's internal pull-up holds the pin high, so the button needs **no resistor**; pressing pulls it low. One press starts the run, a second press stops it (the emergency stop). |
| Ground | any GND | common ground rail |

The servo takes its 5 V power from the Pi's 5 V rail (it is small and only moves
the steering linkage); the **drive motor never does**.

## Camera — CSI, not GPIO

The **OV5647 wide-angle camera** is *not* on the diagram because it does not use
any GPIO pin. It connects to the Pi's dedicated **CSI camera port** with a flat
**CSI ribbon cable**:

```
OV5647 wide camera ──[ CSI ribbon cable ]──► Raspberry Pi 4  CAMERA (CSI) port
```

- Ribbon length must reach from the camera mast down to the Pi (~15 cm on our car).
- Contacts face the correct way at both ends — on the Pi the **blue backing faces
  the Ethernet/USB side**.
- The camera is mounted **upside-down** on the mast, which is corrected in software
  (180° rotation in [`src/camera.py`](../src/camera.py)), not by rewiring.
- It draws its power over the CSI cable — no separate supply.

## Notes / cautions

- **Battery voltage vs driver rating.** The L9110S is rated **2.5–12 V**. Three
  18650 cells in series read ~**12.6 V fully charged**, which is marginally above
  that rating; it sits within spec for most of the run as the pack drops toward
  11 V. Worth watching if the driver runs hot.
- The motor's usable voltage is the battery minus the L9110S's internal drop
  (~1.5–1.8 V), which is why a healthy pack matters for pulling away from rest.
- Recommended: a ~1000 µF capacitor across the L9110S `VCC`–`GND` to absorb
  switching spikes.
- **Never** switch the motor directly from forward to reverse — the software
  enforces a coast-and-settle first (`STOP_FLIP_DELAY`), because the back-EMF
  spike can destroy the Pi's regulator.

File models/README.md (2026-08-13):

# models — 3D-printed parts and CAD

## Full assembly

<p align="center">
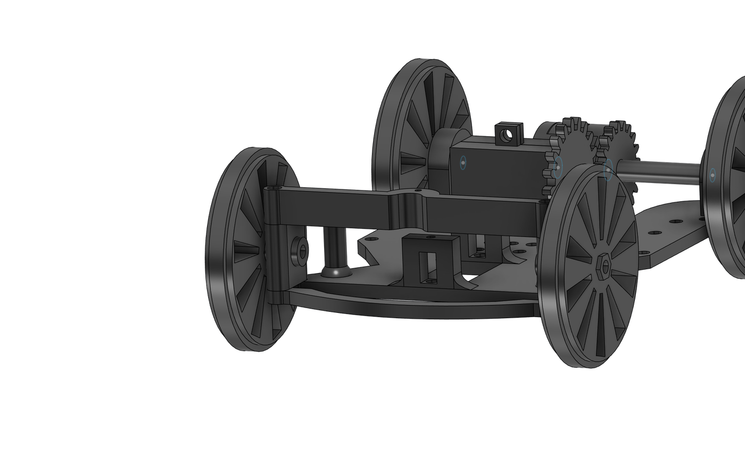
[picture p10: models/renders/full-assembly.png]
Full car assembly, angled view
  
</p>

Front Ackermann steering axle on the left, rear differential axle with the N20
motor and gear cluster on the right.

## Front steering assembly

<p align="center">
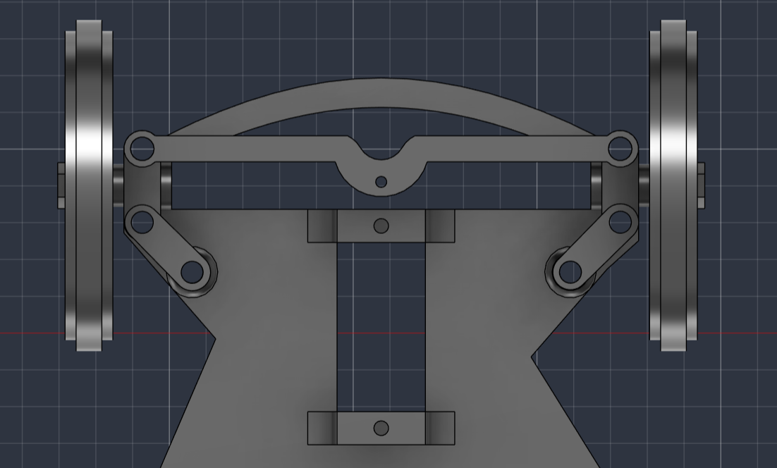
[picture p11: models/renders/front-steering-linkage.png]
Front steering linkage, top view
  
  Chassis, steering centred
  Chassis, steering turned
</p>

A single MG90S servo drives a central bell-crank through a tie-rod to both
steering knuckles, so the inner wheel turns more sharply than the outer one
through a corner. Mechanical limit **±35°**.

## Rear axle and differential

<p align="center">
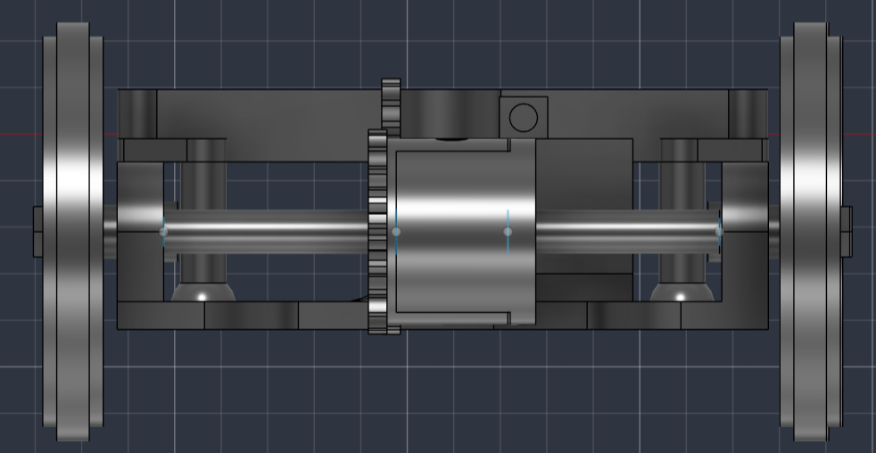
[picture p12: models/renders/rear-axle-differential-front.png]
Rear axle, front view
  
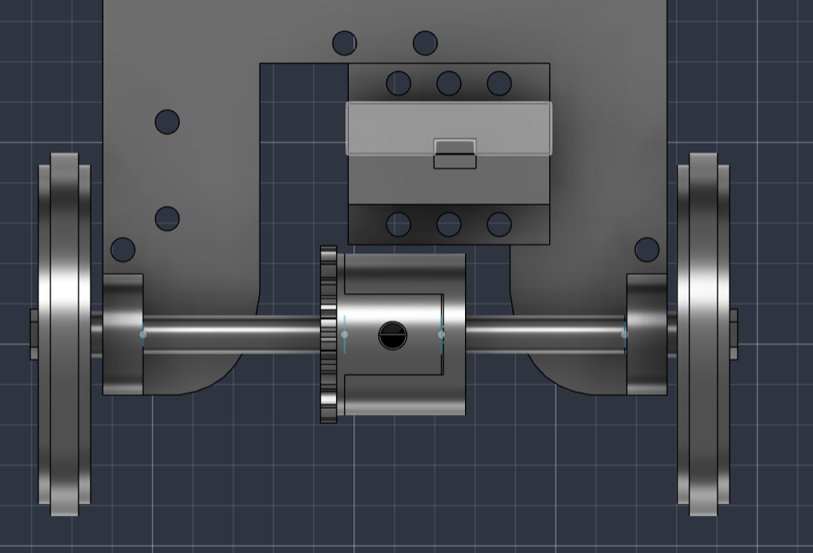
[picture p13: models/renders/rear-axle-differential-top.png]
Rear axle, top view
  
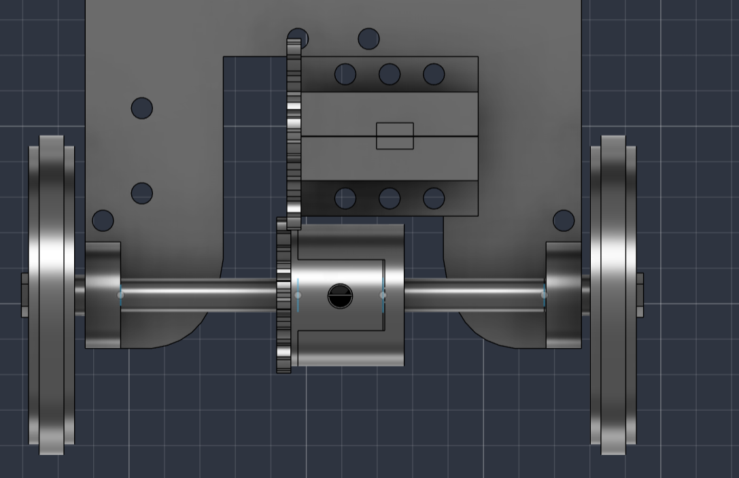
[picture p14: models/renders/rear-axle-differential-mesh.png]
Differential gear mesh detail
  
</p>

An **N20 gear motor (12 V, 200 rpm)** drives the axle through a **25:20 spur
pair (1.25:1)** into the differential. The differential lets the driven wheels
turn at different speeds through a corner, which is what allows the full ±35°
of steering — an earlier solid axle scrubbed and forced the software limit
down to ~8°. See [`../Documentation.pdf`](../Documentation.pdf).

## Chassis

<p align="center">
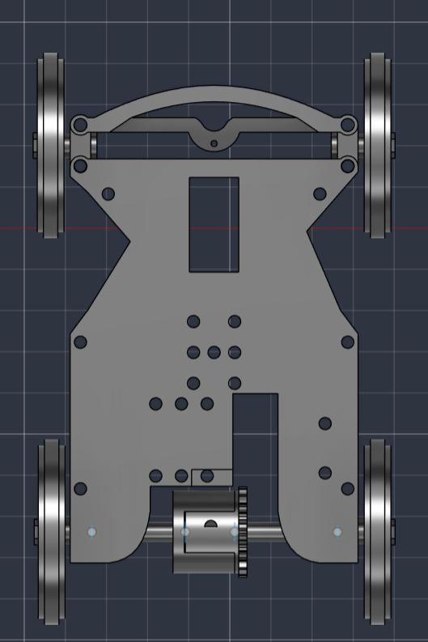
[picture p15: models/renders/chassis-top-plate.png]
Base plate, mounting holes
  
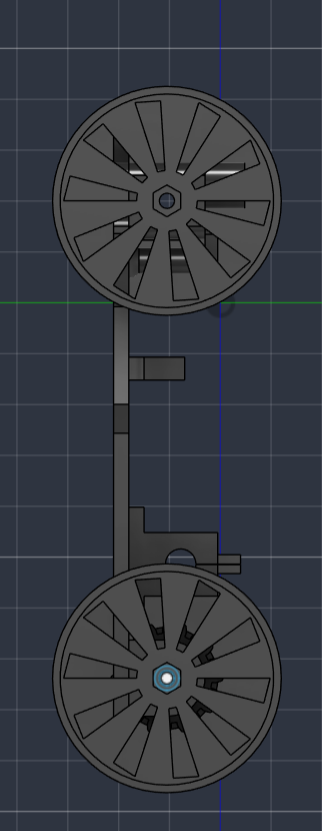
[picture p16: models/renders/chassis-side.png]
Side profile
  
</p>

The base plate's hole grid carries the Raspberry Pi, the L9110S driver, the
buck converter and the battery holder; the camera mast bolts to the front.

## Manufacturing

| | |
|---|---|
| **CAD** | Fusion 360 |
| **Printer** | Bambu Lab A1 |
| **Material** | PLA+ Silk Silver |

## Bill of materials — 3D-printed parts

All printed parts, quantities, and whether each is a fixed or moving part
(from `3d-parts/Mechanical-BOM.docx`). All parts are **PLA+**.

| Part | Qty | Fixed / Moving | Photo |
|---|---|---|---|
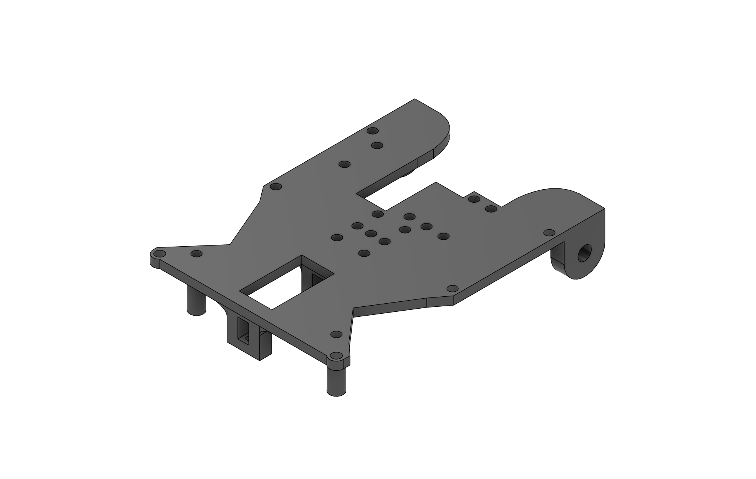
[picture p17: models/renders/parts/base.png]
| Base | 1 | Fixed |  |
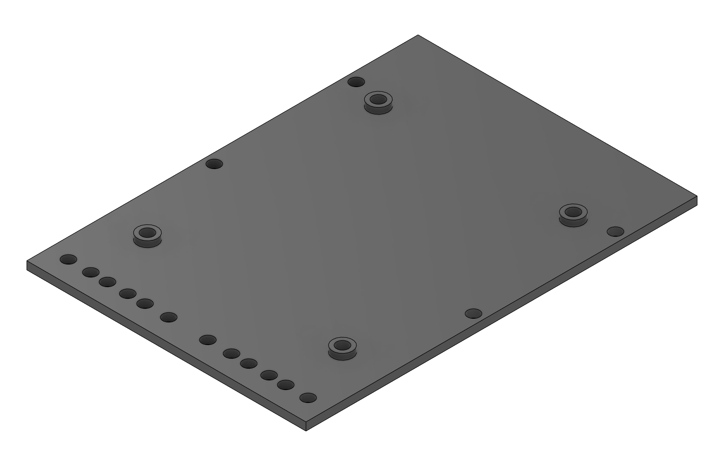
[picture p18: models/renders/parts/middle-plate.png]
| Middle plate | 1 | Fixed |  |
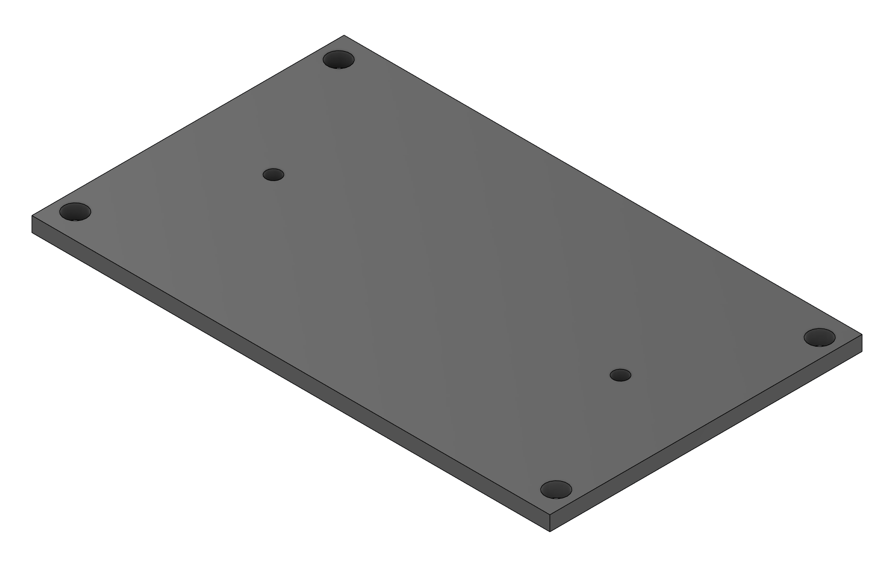
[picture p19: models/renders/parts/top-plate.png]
| Top plate | 1 | Fixed |  |
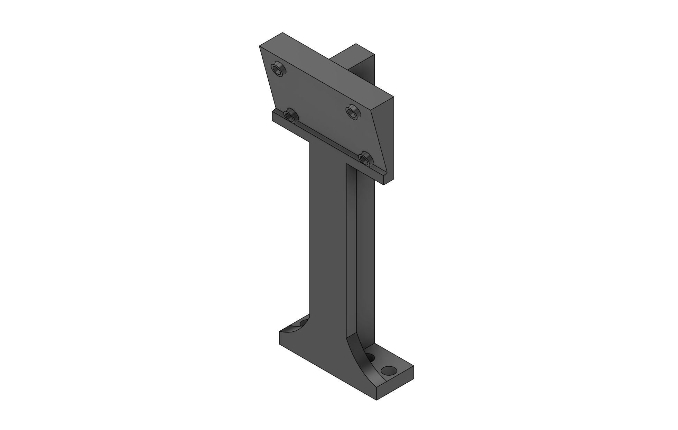
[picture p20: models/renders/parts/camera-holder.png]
| Camera holder | 1 | Fixed |  |
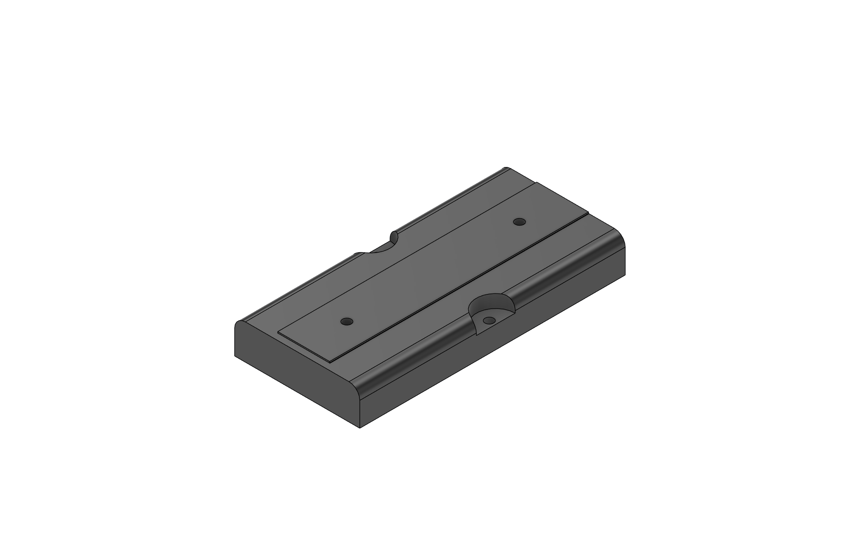
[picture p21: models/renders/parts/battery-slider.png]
| Battery slider p1 | 1 | Fixed |  |
| Battery slider p2 | 1 | Moving | _<photo: battery slider p2 — mating half not yet photographed separately>_ |
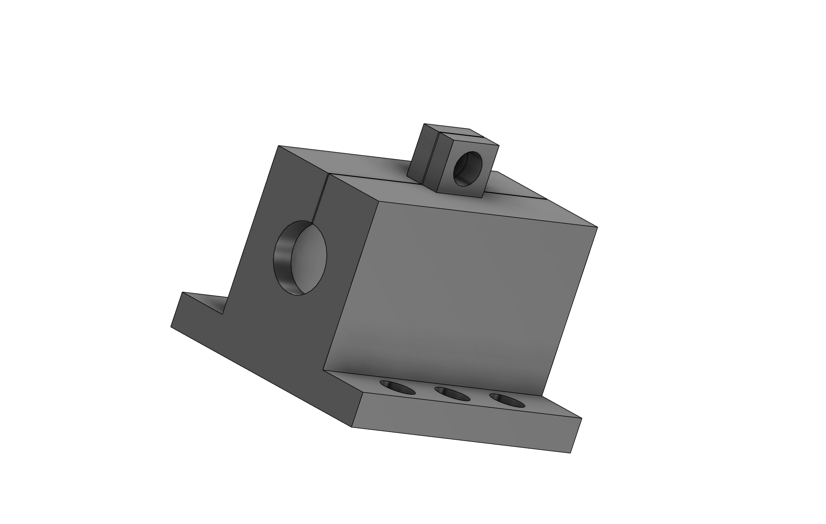
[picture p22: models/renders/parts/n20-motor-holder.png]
| N20 motor holder | 1 | Fixed |  |
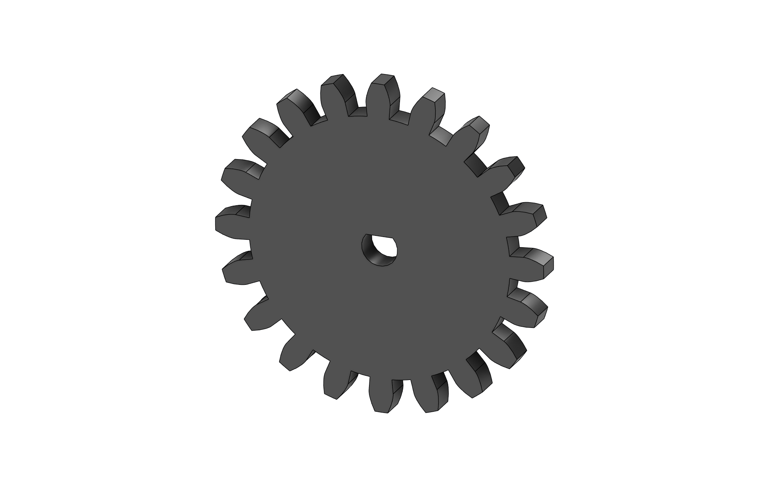
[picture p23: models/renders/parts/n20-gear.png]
| N20 gear | 1 | Moving |  |
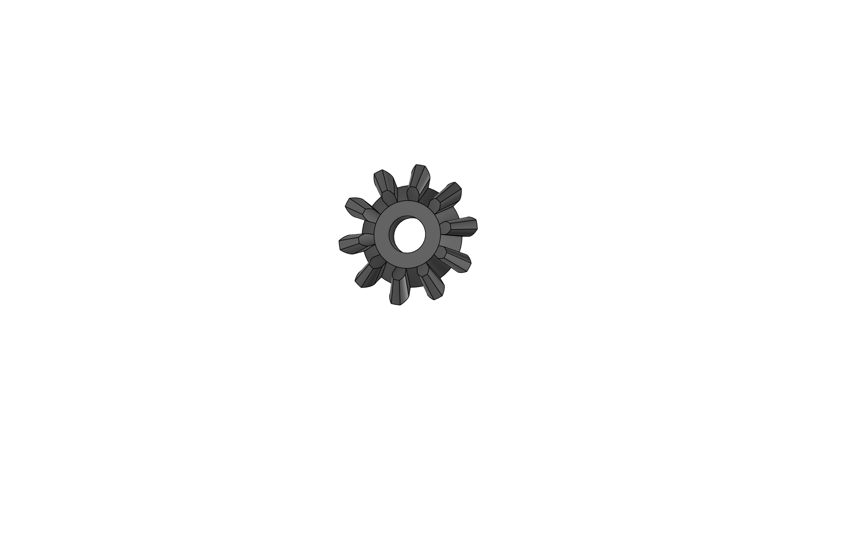
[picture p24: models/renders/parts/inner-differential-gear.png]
| Inner differential gear | 2 | Moving |  |
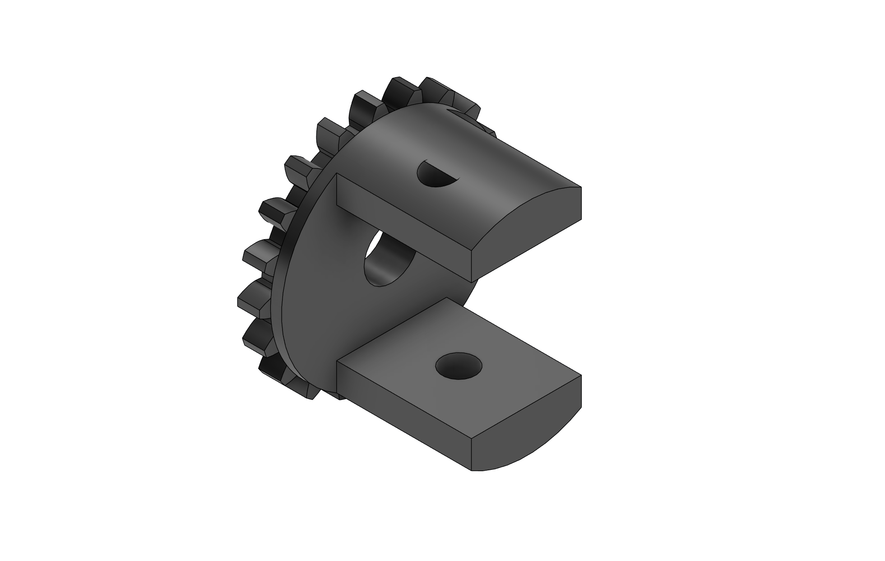
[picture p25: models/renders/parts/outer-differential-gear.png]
| Outer differential gear | 1 | Moving |  |
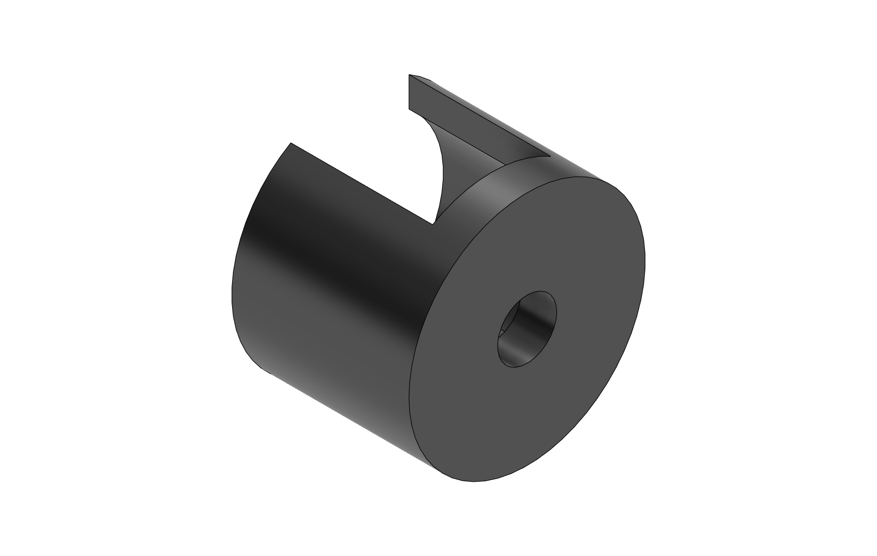
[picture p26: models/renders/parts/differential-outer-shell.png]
| Differential outer shell | 1 | Fixed |  |
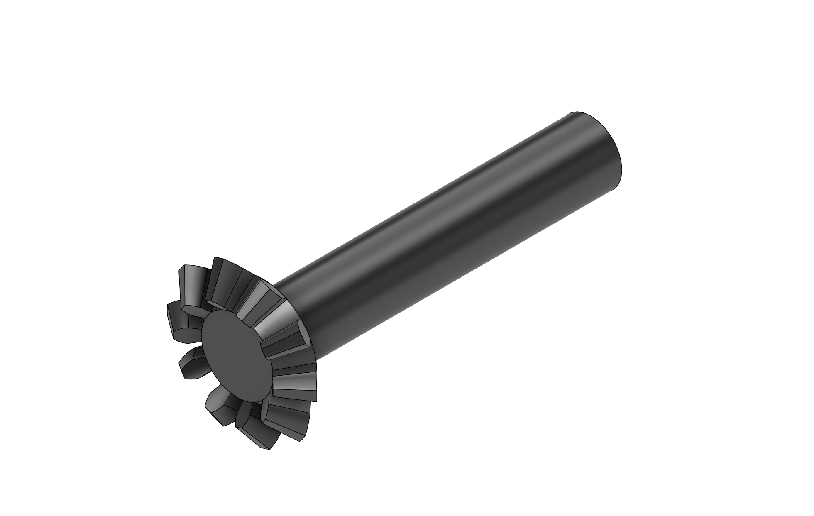
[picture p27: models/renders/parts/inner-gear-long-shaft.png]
| Inner gear with long shaft | 1 | Moving |  |
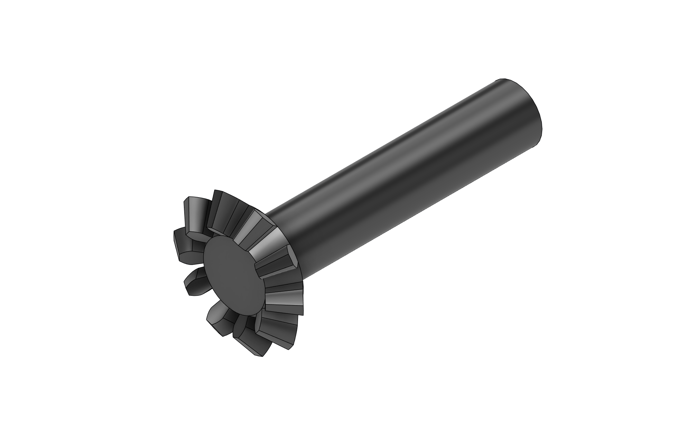
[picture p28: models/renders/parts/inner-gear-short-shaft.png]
| Inner gear with short shaft | 1 | Moving |  |
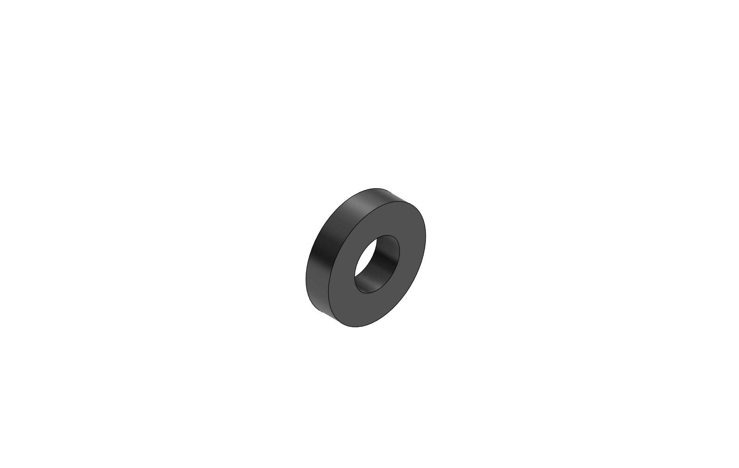
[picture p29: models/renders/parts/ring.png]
| Ring | 2 | Moving |  |
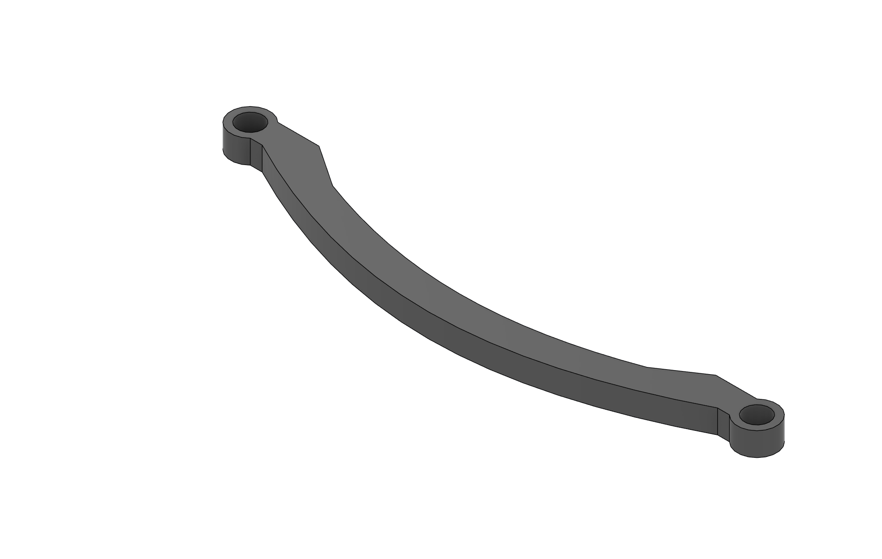
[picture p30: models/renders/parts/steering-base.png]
| Steering base | 1 | Moving |  |
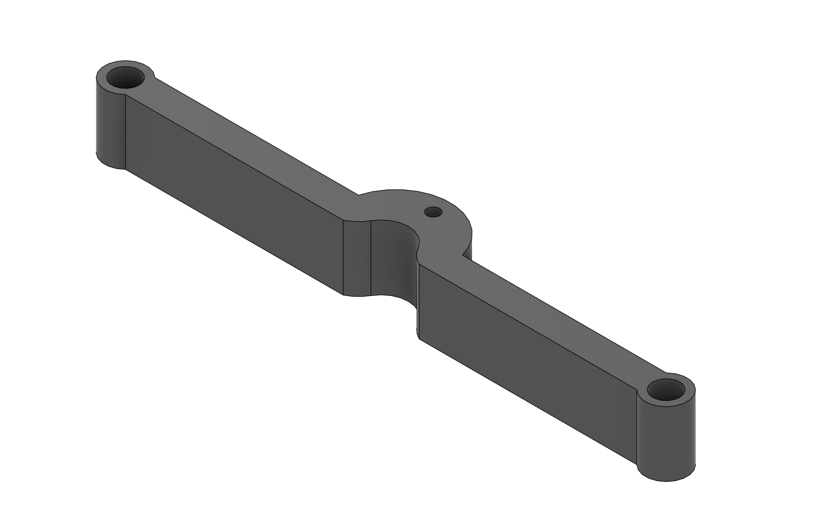
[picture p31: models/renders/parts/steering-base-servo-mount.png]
| Steering base servo mount | 1 | Moving |  |
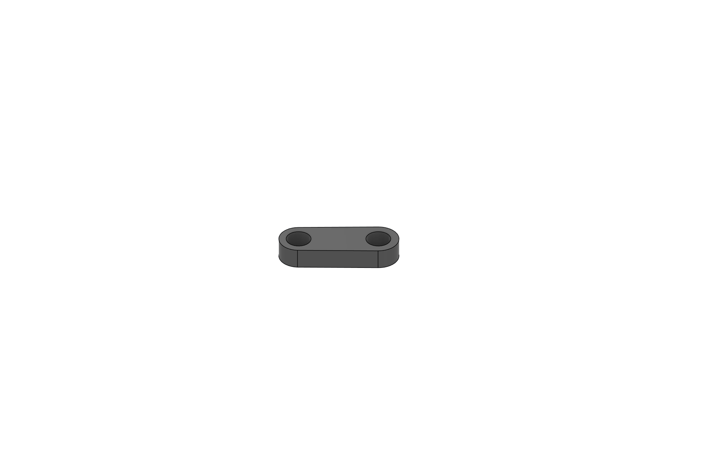
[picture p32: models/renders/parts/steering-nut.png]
| Steering nut | 2 | Moving |  |
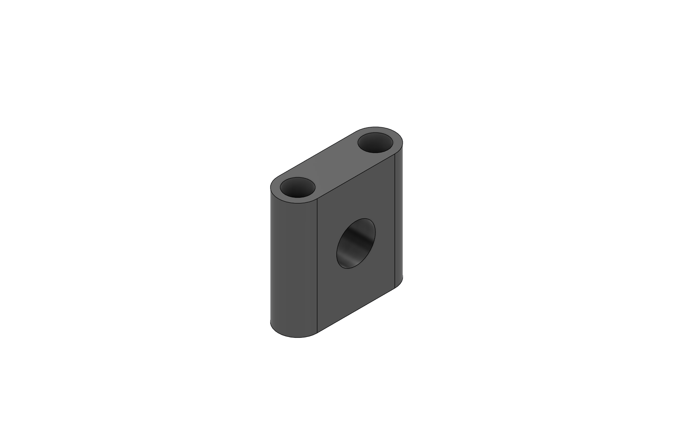
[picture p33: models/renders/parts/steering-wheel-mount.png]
| Steering wheel mount | 2 | Moving |  |
| Wheel | 4 | Moving |  |
| Wheel mount to shaft | 4 | Moving | _<photo: wheel mount to shaft>_ |

**Print note:** moving parts need lubrication to reduce friction — we use
Vaseline on all mating surfaces listed as "Moving" above.

## Fasteners and spacers

| Part | Spec | Qty |
|---|---|---|
| Screw | M3 × 8 mm | 18 |
| Screw | M3 × 20 mm | 4 |
| Standoff, male–female | brass, 25 mm | 4 |
| Standoff, female–female | brass, 20 mm | 4 |

## Folder contents

```
models/
├── renders/       # CAD renders (above)
│   └── parts/     # individual per-part renders, used in the BOM photo column
├── 3d-parts/      # source CAD — individual part STLs, by subassembly, + Mechanical-BOM.docx
└── printing/      # 5 pre-sliced 3MF plates, ready to print on the Bambu Lab A1
```

> **To add:** the full Fusion 360 assembly file, a separate photo for battery
> slider p2 (its mating half), and a photo for the wheel-to-shaft mount.

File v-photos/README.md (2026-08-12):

# v-photos — vehicle photos

Six views of the car, Team The Red Castle.

| View | File | What it shows |
|---|---|---|
| Front | [front.jpg](front.jpg) | OV5647 wide camera on its mast, front Ackermann steering axle |
| Back | [back.jpg](back.jpg) | Raspberry Pi 4 ports, rear drive axle and motor coupling |
| Left | [left.jpg](left.jpg) | Side profile — camera height/tilt, Pi deck, battery on top |
| Right | [right.jpg](right.jpg) | Side profile — power switch, 5 V regulator, drive gear |
| Top | [top.jpg](top.jpg) | Battery pack, camera mast, overall footprint |
| Bottom | [bottom.jpg](bottom.jpg) | Chassis underside — steering servo + linkage, motor, drive gear |

Key details visible: the camera is centred and forward-facing on a rigid mast
(12.5 cm above the mat, tilted ~15° down), the steering servo drives an Ackermann
linkage on the front axle, and the drive motor turns the rear axle through a spur
gear. The Pi sits on its own deck with a separate 5 V regulator below, keeping the
motor supply on its own rail (see the wiring notes in [`../schemes/`](../schemes)).

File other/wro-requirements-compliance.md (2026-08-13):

# WRO 2026 Future Engineers — official requirements & our compliance

Source: *WRO Future Engineers Category – Game Rules 2026*, **§7 (Engineer's
documentation on GitHub)** and **Appendix C (Engineering Journal and
Documentation Requirements)**.

---

## A. What must be submitted

| # | Requirement (rules §7) | Status |
|---|---|---|
| 1 | Documentation uploaded to a **public GitHub repository** | ✅ done |
| 2 | **Hard copy** of the documentation submitted at the international final | ✅ print `Documentation.pdf` |
| 3 | A structured **Engineering Journal (PDF or similar)** — Appendix C.2 | ✅ `Documentation.pdf`, built via `build_pptx_journal.py` in last year's team template/structure |
| 4 | Discussion/motivation for **mobility**, **power & sense**, and **obstacle management** | ✅ README §3, §4, §5 |
| 5 | Photos of the vehicle **from every side, top and bottom** | ✅ `v-photos/` (6 photos) |
| 6 | **Team photo** | ✅ `t-photos/` (member + group photos) |
| 7 | **YouTube URL**, driving autonomously, **≥30 s** of driving, **one video per challenge** | ✅ `video/video.md` |
| 8 | Repository with the **code for all programmed components** | ✅ `src/` |
| 9 | May include **3D printer / laser / CNC model files** | ✅ `models/` — 20 part STLs, 5 sliced 3MF plates, source BOM |
| 10 | **README.md ≥ 5000 characters**, in English | ✅ ~31 000 characters |
| 11 | Code **well documented with comments** | ✅ every module documented |
| 12 | All documentation **in English** (international) | ✅ |
| 13 | Repo **public** from submission and for **≥ 12 months** after | ✅ public |

## B. Commit history rule

The rules require **at least 3 commits**, with deadlines relative to the competition:

| Commit | Deadline | Content requirement |
|---|---|---|
| 1st | no later than **2 months** before | must contain **≥ 1/5** of the final code |
| 2nd | no later than **1 month** before | — |
| 3rd | no later than **2 weeks** before | **this is the one used for scoring** |

> ⚠️ **Action required:** we currently have 15+ commits, but they all date from the
> final build period. Check these dates against your actual competition date — if
> the 2-month/1-month milestones have passed, raise it with your organiser now.
> Also note the rules state that **changes made after the scoring commit may not be
> counted**, so everything important must be in the repository by that date.

The repository link must be submitted **no later than 3 weeks before** the
competition (organisers announce the exact date).

## C. Scoring rubric (Appendix C) — 5 criteria × 6 points = **30 points**

| Score | Meaning |
|---|---|
| **6** | Advanced engineering — fully justified decisions, testing, trade-offs, systems thinking |
| **4** | Competent engineering — clear, structured, reproducible |
| **2** | Limited evidence — incomplete or weakly justified |
| **0** | No evidence |

| # | Criterion | What earns a **6** | Where we cover it |
|---|---|---|---|
| 1 | Mobility & Mechanical Design | torque/speed reasoning, trade-offs, testing that changed the design | README §3.2–3.4, journal §6 |
| 2 | Power & Sensor Architecture | power budget, sensor trade-offs, placement justified by **field geometry**, calibration, failure points | README §4.1–4.3, `schemes/` |
| 3 | Software Architecture & Obstacle Strategy | state machine + rationale, justified algorithms, edge cases, testing metrics | README §5.1b–5.1c, §5.7 |
| 4 | Systems Thinking & Engineering Decisions | explicit constraints, trade-offs, iteration, risk & mitigation, "we chose X instead of Y" | README §5.6, §5.8, journal |
| 5 | Reproducibility & GitHub Quality | fully reproducible, clear structure, meaningful commits, testing workflow, **versioning/release notes** | repo structure, README §7 |

### What still separates us from a 6

| Criterion | Gap |
|---|---|
| 1 | A measured (timed) real top speed, not just the theoretical no-load figure |
| 2 | Measured current draw (we have datasheet estimates, not a clamp-meter reading) |
| 3 | **Quantitative metrics from real runs** (lap times, success rate over N runs) — the CSV logging is built and used for debugging; a summarised results table across multiple runs is not yet written up |
| 4 | A documented version history (v1 → v2 → v3) of the mechanical design specifically, beyond what the journal already narrates |
| 5 | A tagged release (`v1.0`) on GitHub |

> The rules' own level-6 examples are explicitly **quantitative**, e.g. *"increased
> lap consistency from 60 % to 85 % over 20 runs"* and *"reduced misdetection by
> 40 %"*. Numbers from real testing are the single highest-value thing left to add.

## D. Notes

- **Appendix D** (minimal component set — encoder, IMU, distance sensors, etc.) is
  explicitly *"a suggestion rather than the requirements"*, so our camera-only
  design is fully compliant.
- The rules state: *"The main source for scoring points is the GitHub repository."*
  The hard copy is a backup if the repo is unreachable, and helps judges track
  teams during the competition.
- An official template exists at
  `github.com/World-Robot-Olympiad-Association/wro2022-fe-template`; our structure
  follows it (`src`, `models`, `schemes`, `t-photos`, `v-photos`, `video`, `other`).

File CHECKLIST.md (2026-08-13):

# Submission Checklist — Team The Red Castle

**📷 = only you can do it · 🤖 = Claude can do/commit.**

## Done
- [x] Official WRO repo structure (`src`, `models`, `schemes`, `t-photos`, `v-photos`, `video`, `other`)
- [x] Engineering `README.md` (mobility, power/sense, camera/vision, both algorithms, setup/run) — current with the final `src/`
- [x] All control code + tools in `src/`
- [x] Bill of Materials (`other/bill-of-materials.md`)
- [x] Public repo pushed

## 🔴 Mandatory for judging
- [x] 📷 `v-photos/` — 6 vehicle photos (front, back, left, right, top, bottom)
- [x] 📷 `t-photos/` — 4 member photos + 2 group photos
- [x] 🎥 `video/video.md` — Open Challenge + Obstacle Challenge YouTube links added
- [x] 🖼️ `schemes/` — wiring diagram image (Pi ↔ L9110S ↔ servo ↔ power, common ground)
- [x] 🧩 `models/3d-parts/` — 20 part STLs (5 subassemblies) + Mechanical-BOM.docx + CAD renders (full assembly, steering, rear axle/differential)
- [x] 🧩 `models/printing/` — 5 sliced 3MF plates, ready to print
- [x] ✍️ Team names + roles in `README.md`
- [x] ✍️ Bio + email for each member — filled in README §12
- [x] **Engineering Journal — `Documentation.pdf`**, built in last year's template/structure with our current, accurate content (source: `build_pptx_journal.py` -> gitignored `Documentation.pptx` -> exported PDF)

## 🟡 Recommended (higher documentation score)
- [ ] 🤖 Wiring pin-table / ASCII schematic in `schemes/` (text backup to the image)
- [ ] 🤖 Assembly / build-steps section
- [x] 🤖 Engineering journal narrative (design process, iterative debugging) — folded into `Documentation.pdf`'s Evolution section
- [x] 🤖 BOM: battery (3×18650), buck converter, MG90S servo confirmed from the wiring diagram
- [x] 🤖 BOM: N20 motor (12 V 200 rpm), differential, 25:20 gears, PLA+ Silk Silver / Bambu A1 / Fusion 360, Pi 2 GB
- [x] 🤖 BOM: 20-part printed-parts table with quantities and fixed/moving status
- [x] 🤖 BOM: fasteners (M3×8 ×18, M3×20 ×4) and brass spacers (M-F 25 mm ×4, F-F 20 mm ×4)
- [x] 🤖 BOM: total cost (≈ $120)
- [x] 📏 Measurements: mass (407 g), wheel diameter (4.7 cm), wheelbase (9.4 cm), track (8.5 cm), dimensions (14.2×9.3×15 cm), camera height/tilt, servo trim (−9°)
- [x] 🤖 Commit reference `colors.json`, `camera_settings.json`, `servo_center.txt` in `src/`
- [ ] 📏 Measured (timed) real max speed — deliberately left as the theoretical figure; not being chased further
- [x] 🤖 BOM part photos — 17/20 printed parts photographed individually in `models/renders/parts/` and filled into the BOM table; 2 gaps remain (battery slider p2, wheel-mount-to-shaft) noted at the bottom of `models/README.md`
- [ ] 📷 Full Fusion 360 assembly file (`.f3d`/`.step`)
- [ ] 🤖 Tag a `v1.0` GitHub release once everything below is settled

## ⚙️ Competition readiness
- [x] Color tuning (blue, orange, green, red, magenta) calibrated on the real field
- [x] White balance / exposure locked (`camera_settings.json`)
- [x] Open Challenge field-tested, both directions, completes and stops correctly
- [x] Obstacle Challenge field-tested — sign passing + lane keeping between signs work
- [x] Both challenge runs recorded and uploaded
- [ ] **Known open issue:** shadow at two of four corners occasionally misread as wall — diagnosed (`tools/shadow_check.py`), not yet fully closed out
- [ ] **Known gap:** parking is not wired into the Obstacle Challenge main loop yet (magenta is treated as a wall to avoid, not a target)

## Info still needed from you
- [ ] Total build cost — ~~needed~~ **received: ≈ $120** ✓
- [ ] Fastener/spacer BOM — ~~needed~~ **received** ✓
- [ ] Servo trim — ~~needed~~ **received: −9°** ✓
- [ ] Fusion assembly file — ~~BOM part photos~~ **received, 17/20 filled** ✓ (2 small gaps noted above)
- [ ] Real measured max speed — explicitly not required per your instruction

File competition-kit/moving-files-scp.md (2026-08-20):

# Moving files between the laptop and the Pi

Everything here is `scp`, run **from the laptop**, in **Git Bash** (not
PowerShell — see the gotchas at the end).

The shape is always the same:

```
scp  <where it is now>  <where it should go>
```

and a remote place is written `pi@raspberrypi:path`.

---

## The four you will actually use

### Send one file to the Pi

```bash
scp src/open_challenge.py pi@raspberrypi:wro2026/
```

The trailing `/` means "into that directory, keep the name". Without it you are
naming the destination file, which is how you accidentally create
`wro2026/open_challenge` with no extension.

### Send a whole folder

```bash
scp -r src/tools pi@raspberrypi:wro2026/
```

`-r` is recursive. Note this puts it at `wro2026/tools`, and if `tools` already
exists it **merges into it**, overwriting same-named files.

### Fetch one file from the Pi

```bash
scp pi@raspberrypi:wro2026/logs/open_log.csv diag/
```

### Fetch everything matching a pattern

```bash
scp "pi@raspberrypi:wro2026/logs/obstacle_*.csv" diag/obs/
```

**Quote the remote pattern.** Unquoted, your laptop's shell tries to expand
`*.csv` locally, finds nothing, and the command fails. Quoted, the `*` reaches
the Pi and expands there.

---

## The project's own shortcuts

You rarely need raw `scp` — the repo has wrappers:

```bash
./sync.sh push          # laptop -> Pi   (src/, tools/, docs/)
./sync.sh pull          # Pi -> laptop
./backup.sh save        # full snapshot of the Pi into backups/
```

> `./sync.sh push` **overwrites** whatever is on the Pi. If you tuned numbers on
> the Pi, `./sync.sh pull` first, or those edits are gone. This has bitten us:
> always check with a diff before pushing.

Check before you overwrite:

```bash
scp pi@raspberrypi:wro2026/obstacle_challenge.py /tmp/theirs.py
diff src/obstacle_challenge.py /tmp/theirs.py
```

---

## Useful variations

| What you want | Command |
|---|---|
| Keep timestamps | `scp -p file pi@raspberrypi:wro2026/` |
| See progress on a big file | `scp -v file pi@raspberrypi:wro2026/` |
| Several files at once | `scp a.py b.py c.py pi@raspberrypi:wro2026/tools/` |
| A file with spaces in the name | `scp "my file.png" pi@raspberrypi:wro2026/` |
| From the Pi's home directory | `pi@raspberrypi:wro2026/...` — paths are relative to `/home/pi` |
| An absolute path on the Pi | `pi@raspberrypi:/boot/firmware/config.txt` |

### Faster for many files: rsync

`scp` re-sends everything. `rsync` sends only what changed:

```bash
rsync -av --progress src/tools/ pi@raspberrypi:wro2026/tools/
```

The **trailing slash on the source matters**: `src/tools/` copies the *contents*
into `tools/`; `src/tools` would create `tools/tools`.

---

## Running something without copying it

Often you do not need to copy at all:

```bash
ssh pi@raspberrypi "cd wro2026 && source .venv/bin/activate && python tools/wall_calib.py cw"
```

And to pull a file straight into a local one:

```bash
ssh pi@raspberrypi "cat wro2026/logs/open_log.csv" > diag/open_log.csv
```

---

## Gotchas on THIS setup

These are all things that have actually gone wrong here.

### 1. Use Git Bash, not PowerShell

PowerShell has its own `scp`, but the quoting differs and remote globs behave
badly. Every command in this repo assumes Git Bash.

### 2. `/tmp` is not the same place in both shells

Git Bash's `/tmp` maps to a Windows temp folder that **Python cannot see** at
that path. So this fails:

```bash
scp pi@raspberrypi:wro2026/file.py /tmp/f.py    # lands in Git Bash's /tmp
python -c "open('/tmp/f.py')"                   # Python: file not found
```

Copy into the repo (e.g. `diag/`) instead, or use a full Windows path.

### 3. The hostname is not always resolvable

Measured on this laptop:

```
raspberrypi        -> works on the hotspot (Windows ICS DNS)
raspberrypi.local  -> FAILS from Git Bash (no mDNS there)
```

and it is intermittent — `scp` has failed with *"Could not resolve hostname
raspberrypi"* seconds after a successful one. If that happens, **just retry**;
it usually works on the second attempt. If it keeps failing, the Pi is off, or
the hotspot is down, or a VPN (ProtonVPN) is hijacking DNS — disconnect it.

Over the direct Ethernet cable, see `new-laptop-setup.md` for the hosts entry.

### 4. Line endings

Windows Git may write CRLF into files. Python does not care, but a **shell
script** with CRLF fails on the Pi with a confusing `bad interpreter` error. If
a `.sh` you copied misbehaves:

```bash
ssh pi@raspberrypi "cd wro2026 && sed -i 's/\r$//' tools/venue_net.sh && chmod +x tools/venue_net.sh"
```

### 5. The executable bit is lost

`scp` from Windows does not carry the executable bit, so a copied `.sh` or tool
arrives non-executable:

```bash
ssh pi@raspberrypi "chmod +x wro2026/*.sh wro2026/tools/*.py"
```

### 6. Do not copy over a running program

If `obstacle_challenge.py` is running and holding the camera and GPIO, copying a
new version does **not** affect the running one — but the next run uses the new
file, so it is easy to think you tested a change you did not. Check first:

```bash
ssh pi@raspberrypi "ps -eo pid,etime,cmd | grep -E 'open_challenge|obstacle_challenge' | grep -v grep"
```

---

## Verifying a copy actually landed

Byte counts and a content compare, ignoring line endings:

```bash
ssh pi@raspberrypi "wc -c < wro2026/open_challenge.py"
wc -c < src/open_challenge.py

diff <(tr -d '\r' < src/open_challenge.py) \
     <(ssh pi@raspberrypi "cat wro2026/open_challenge.py" | tr -d '\r') \
  && echo IDENTICAL
```

An md5 comparison will show a **false difference** if one side has CRLF and the
other LF — strip `\r` from both first, as above.

---

## Where things live on the Pi

```
/home/pi/wro2026/
    open_challenge.py            the two programs
    obstacle_challenge.py
    openchallengejoliancompetetionday.py    your own copy
    run.sh  autostart.sh         what the boot service runs
    robot.py config.py camera.py the older library (tools import these)
    colors.json  camera_settings.json  servo_center.txt   settings, read by name
    tools/                       tuning and diagnostic tools
    tools/scratch/               one-off probes, kept for reference
    logs/                        one timestamped CSV per run
    frames/                      captured images
    old/  docs/  color_check/    archive
    .venv/                       the Python environment - never copy over this
```

> **Never `scp` into `.venv/`** and never `sync.sh push` something that would
> overwrite it. Rebuilding it at a venue with no internet is not possible.

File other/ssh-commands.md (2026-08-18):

# Terminal commands — moving code and files to and from the Pi

Every command here is copy-pasteable. Run them from the repo folder on the
laptop unless it says otherwise.

```
laptop folder :  C:\Users\jolian\Desktop\WRO Future Engineers 2026
Pi folder     :  /home/pi/wro2026     (written below as ~/wro2026)
login         :  pi@raspberrypi
```

---

## The three you will actually use

```bash
./sync.sh pull        # Pi  ->  laptop   (grab what you tuned over SSH)
./sync.sh push-safe   # laptop -> Pi     (runs the tests first, refuses if they fail)
./backup.sh save "it worked"
```

> **`pull` before you edit.** You tune values directly on the Pi between runs.
> `push` overwrites them — that is what `push` means. Pull first, or lose them.

---

## Connecting

```bash
ssh pi@raspberrypi
```

If the name does not resolve:

```bash
ssh pi@raspberrypi.local      # mDNS
ssh pi@192.168.50.1           # over the Ethernet cable
```

Run one command and come straight back:

```bash
ssh pi@raspberrypi 'cd ~/wro2026 && ls'
```

Run something in the virtual environment (needed for anything using the camera):

```bash
ssh pi@raspberrypi 'source ~/wro2026/.venv/bin/activate && cd ~/wro2026 && python tools/test_logic.py'
```

---

## Copying files

**`scp` = secure copy. The direction is whichever way the arrow of the arguments
points: `scp FROM TO`.**

### Laptop → Pi

```bash
scp src/robot.py pi@raspberrypi:wro2026/                    # one file
scp src/*.py pi@raspberrypi:wro2026/                        # several
scp src/tools/*.py pi@raspberrypi:wro2026/tools/            # into a subfolder
scp -r src/tools pi@raspberrypi:wro2026/                    # a whole folder
```

### Pi → laptop

```bash
scp pi@raspberrypi:wro2026/colors.json src/                 # one file
scp pi@raspberrypi:wro2026/logs/*.csv logs-from-pi/         # all the logs
scp -r pi@raspberrypi:wro2026/frames ./frames-from-pi       # a whole folder
```

> The Pi path `wro2026/...` is relative to `/home/pi`, so `wro2026/colors.json`
> and `/home/pi/wro2026/colors.json` are the same file.

### The newest log, without knowing its name

```bash
scp "pi@raspberrypi:$(ssh pi@raspberrypi 'ls -t ~/wro2026/logs/*.csv | head -1')" .
```

---

## Running a challenge

```bash
ssh pi@raspberrypi
cd ~/wro2026 && source .venv/bin/activate
python obstacle_challenge.py     # then PRESS THE BUTTON
```

Or with the runner, which takes the program name from one line inside itself:

```bash
./run.sh
./run.sh open_challenge.py       # override just this once
```

**Keep it running after you disconnect** — otherwise closing the terminal kills
the run:

```bash
ssh pi@raspberrypi 'cd ~/wro2026 && nohup ./run.sh > run.log 2>&1 &'
ssh pi@raspberrypi 'tail -f ~/wro2026/run.log'      # watch it
```

---

## The tools

All of these need the venv, so they are shown with it:

```bash
V='source ~/wro2026/.venv/bin/activate && cd ~/wro2026 &&'

ssh pi@raspberrypi "$V python tools/test_logic.py"      # the brain, offline
ssh pi@raspberrypi "$V python tools/dryrun.py"          # camera live, motor untouched
ssh pi@raspberrypi "$V python tools/button_test.py"     # is the button wired right
ssh pi@raspberrypi "$V python tools/line_check.py"      # what is triggering a line
ssh pi@raspberrypi "$V python tools/park_check.py"      # which way out of the lot
ssh pi@raspberrypi "$V python tools/tune_colors.py --check"
```

Anything that saves a picture leaves it in `~/wro2026`, so bring it back:

```bash
scp pi@raspberrypi:wro2026/line_check.png .
```

---

## Watching a run from the laptop

```bash
ssh pi@raspberrypi 'tail -f ~/wro2026/run.log'          # live output
ssh pi@raspberrypi './wro2026/autostart.sh log'         # if running as a service
```

---

## Housekeeping

```bash
# free space
ssh pi@raspberrypi 'df -h / | tail -1'

# clear old logs and frames before a session
ssh pi@raspberrypi 'rm -f ~/wro2026/logs/*.csv ~/wro2026/frames/*'

# is anything still running?
ssh pi@raspberrypi 'pgrep -af "python.*challenge" || echo "nothing running"'

# stop a runaway program
ssh pi@raspberrypi 'pkill -f "python.*challenge"; echo stopped'

# reboot / shutdown
ssh pi@raspberrypi 'sudo reboot'
ssh pi@raspberrypi 'sudo shutdown -h now'
```

> **Always shut down properly before pulling power.** Yanking it mid-write is
> the classic way to corrupt an SD card, and the card holds the OS, the Python
> environment and every calibration file.

---

## Not typing the password every time

```bash
ssh-keygen -t ed25519 -C "wro-laptop"        # press Enter at every prompt
ssh-copy-id pi@raspberrypi                   # asks for the password ONE last time
ssh pi@raspberrypi                           # ...and never again
```

If `ssh-copy-id` is missing on Windows:

```bash
cat ~/.ssh/id_ed25519.pub | ssh pi@raspberrypi 'mkdir -p ~/.ssh && cat >> ~/.ssh/authorized_keys'
```

---

## When something goes wrong

| symptom | try |
|---|---|
| `Could not resolve hostname` | `ssh pi@raspberrypi.local`, then `ssh pi@192.168.50.1` |
| `Connection timed out` | the Pi is off, rebooting, or off the network |
| `Permission denied` | wrong password, or the wrong user (it is `pi`) |
| `REMOTE HOST IDENTIFICATION HAS CHANGED` | the SD card was reimaged: `ssh-keygen -R raspberrypi` |
| Copied a file but nothing changed | you copied to the wrong folder — it must be `~/wro2026/`, and tools go in `~/wro2026/tools/` |
| Edited on the Pi, then pushed, and lost it | that is what `push` does. `./backup.sh undo` |

### Prove which machine you are on

Easy to lose track in a long session:

```bash
hostname        # "raspberrypi" = the Pi.  Anything else = the laptop.
```

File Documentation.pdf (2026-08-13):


# Engineering Journal

## WRO 2026 Future Engineers — Self-Driving Cars

Team The Red Castle | HMK AI and Robotics Club
Coach: Ahmad Kalthom | Jolian Wassof · Omar Shammout · Louay Rashwan

# Table of Contents

- 1. Introduction
- 2. Solution
- 2.1 Open Challenge 2.2 Obstacle Challenge
- 2.3 Control-Loop Flowchart (Sense & Decide / Act & Loop)
- 2.4 Obstacle Challenge Priority Flowchart
- 3. Mobility Management
- 3.1 The Steering Assembly 3.2 The Driving Assembly
- 3.3 The Robot's Body / 3D Design 3.3b Printed Parts Gallery
- 3.4 Mobility Measurement
- 4. Power and Sense Management
- 4.1 The Robot's Power Source 4.2 Main Components
- 4.2b Why We Chose Each Component
- 4.3 Wiring Diagram 4.4 Sensing
- 5. The Robot's Evolution
- 5.1 Past 5.1a Camera Decision — Proof
- 5.1b/c Vision Testing — Flip, Colour, Masking, Calibration
- 5.2 Present 5.3 Future
- 6. The Vehicle's Photos

# 1. Introduction

Self-driving cars are one of the clearest places where robotics, computer vision and control theory meet in a single physical object that either works or doesn't. For WRO 2026 Future Engineers, our goal was to build a vehicle that finds its own way around a track it has never measured, using only what a camera can see.

We built our car around a Raspberry Pi 4 and a single wide-angle camera. No LiDAR, no ultrasonic rangefinders, no wheel encoders, no IMU. Everything the rules require the car to know — where the walls are, which way to lap, where the traffic signs are, where to park — is visible to a camera, so we put our engineering time into making that one sensor trustworthy instead of into fusing several imperfect ones.

That decision shaped most of what follows. A camera-only car lives or dies on image quality and threshold tuning, and a large part of this document is the story of getting those right: a sensor swap that fixed a depth-of-field problem we didn't expect, a wall detector that turned out to be reading corner lines as walls, and a control law that we rebuilt once we had a correct measurement to calibrate it against.

The vehicle drives the Open Challenge — three laps around a track whose inner wall positions are randomised each round — and the Obstacle Challenge, which adds red and green traffic signs that must be passed on the correct side and a parking manoeuvre at the end.

# 2. Solution

2.1 Open Challenge

The Open Challenge is three laps of a track whose inner wall positions are randomised each round, so nothing about the corridor width can be hard-coded in advance — the car has to read it from the camera as it drives.

- Direction is decided once, from the first corner line the camera sees, and locked for the rest of the run — whichever colour reads bigger in that frame sets clockwise or counter-clockwise, and the reading is cross-checked against which side of the image has more open wall as a second opinion.
- Between corners, a proportional-derivative controller holds a fixed distance to the outer wall only. We deliberately do not centre between both walls: the inner wall moves every round, so the outer wall is the one reference that stays put.
- At a corner, crossing the driving-direction's line fires a scripted turn — full steering lock held for a bounded time, ending as soon as the way ahead reads clear rather than after a fixed duration.
- A wall emergency always wins, in any state: if either wall gets too close the car escapes proportionally to how close it is, and if both walls are close at once (jammed facing a corner) it commits to a single escape direction instead of wavering between two.
- The car stops once 11 quadrants are counted and the lap timer has run out, so it finishes driving through the last straight instead of halting on the line itself.

# 2. Solution

2.2 Obstacle Challenge

The Obstacle Challenge adds red and green traffic signs that must be passed on the correct side, then a parking manoeuvre once the laps are done.

- If a sign is visible, the car steers to place it correctly — red on the car's right, green on its left — with the target position sliding further toward the frame edge as the sign gets closer, so the manoeuvre curves rather than swerving late.
- If a sign was visible a moment ago but drops out of view for a frame, the last steering command is held rather than reacted to — sign detection can flicker sharply between consecutive frames, and reacting to every drop-out broke passes mid-way.
- Between signs, the car falls back to the same outer-wall lane-keeping law used in the Open Challenge, instead of driving straight and hoping a wall override corrects it in time.
- A wall override sits above all of this and also does the job of turning the car through each corner, since there is no separate scripted-turn sequencer here.
- Parking is not yet wired into the main loop — the magenta gate is currently treated purely as a wall to avoid. This is called out honestly in the Evolution section.

# 2. Solution

Start; Capture frame (OV5647, 180° flip); Scripted turn active?; yes

2.3 Control-Loop Flowchart — Sense & Decide

Every frame runs the same read -> decide -> act loop. navigate() in robot.py picks the steering command in this strict priority order.

Crop mat ROI -> 320x160,
median blur, convert HSV

Measure L/R wall density,
front density, line fractions

LapTracker.update:
direction + lap counting

Either wall past
WALL_EMERGENCY?

Proportional escape;
full lock if BOTH walls close

Hold full lock in the
locked direction

Front wall very close
& direction known?

Trigger the turn anyway
(geometry backup)

Outer-wall PD control:
hold distance to ONE wall

G, I, K or L → the steering command continues on “Control-Loop Flowchart — Act & Loop”

# 2. Solution

2.3 Control-Loop Flowchart — Act & Loop

Continues from the steering command chosen on the previous slide (G, I, K or L).

steering command; Clamp to STEER_MAX, set servo; Scale speed down with steering effort, set motor; Log the frame to CSV; Lap count satisfied and timer expired?; Stop: motor 0, servo centre; yes; no — next frame

This priority order is what makes a wall emergency unconditional: it is checked first, every frame, before the turn state or the lane-keeping law ever gets a say. The scripted turn and the geometry backup only run when no wall is already too close.

# 2. Solution

2.4 Obstacle Challenge — Priority Flowchart

Steering is decided by a strict priority, so a lower-priority behaviour can never override safety.

Every frame; Sign visible?; Steer to place it correctly: red on our right, green on our left; No, but seen recently: hold last manoeuvre (SIGN_MEMORY); No sign at all: fall back to outer-wall lane keeping; Outer wall past WALL_EMERGENCY?; Full lock away from the wall —; overrides everything, also turns corners; Use the steering chosen above; yes; no, recent

Priority, highest to lowest: (1) wall override — also turns every corner, (2) sign steering, (3) sign-hold memory for detection flicker, (4) outer-wall lane keeping between signs.

# 3. Mobility Management

3.1 The Steering Assembly

Steering is Ackermann-style, driven by a single MG90S micro servo (GPIO13, which is a hardware-PWM pin — a smoother, lower-jitter signal than a software-timed one).

The servo turns a central bell-crank, which pushes a tie-rod out to both front steering knuckles. Because the linkage geometry is Ackermann and not a simple parallel arm, the inner wheel turns through a sharper angle than the outer one in a corner — each wheel follows its own turning radius instead of fighting the other and scrubbing.

The linkage's mechanical limit is ±35°. In software we run it at ±20° (STEER_MAX in config.py) for stability at full driving speed — the wider mechanical range is there if a future tuning pass wants it.

Every steering command in the codebase passes through this one constant and one servo() function, so there is exactly one place that ever needs to know the true centre position — the field-calibrated trim is stored in servo_center.txt (currently -9°) and applied automatically.


Front steering linkage, top view

Steering turned, showing the linkage sweep

# 3. Mobility Management

3.2 The Driving Assembly

Drive comes from an N20 geared DC motor rated 12 V, 200 rpm, chosen for its compact size and enough torque to pull the car away from rest repeatedly without stalling.

The motor is controlled by an L9110S dual H-bridge, wired so one input is held low while the other carries the PWM speed signal (GPIO24 = forward, GPIO23 = reverse). In software, motor() never switches directly from forward to reverse — it coasts to a stop and waits first, because slamming the direction while the motor is still spinning drives its back-EMF onto the supply rail and can destroy the Pi's regulator. We found this out by losing a regulator early in the build.

From the motor, a 25-tooth pinion drives a 20-tooth gear (a 1.25:1 reduction) into a 3D-printed differential we designed ourselves — outer shell, outer ring gear, and two inner bevel gears on long and short shafts. The differential is the single change that let us raise the steering limit: with a solid axle, the outer wheel scrubbing against the inner one through a corner cost so much traction we had to cap steering near 8° just to keep the car from stalling mid-turn.


N20 motor driving the differential gear mesh


Rear axle, front view

# 3. Mobility Management

3.3 The Robot's Body / 3D Design

The chassis was designed in Fusion 360 and printed in PLA+ Silk Silver on a Bambu Lab A1: a base plate, a middle plate and a top plate carrying the Pi, battery, driver, buck converter and the camera mast, sized to keep mass low and central over the wheelbase.


Full car assembly

Mass 407 g, overall footprint 14.2 x 9.3 x 15 cm, wheelbase 9.4 cm, rear track 8.5 cm — a wheelbase-to-track ratio close to 1:1, a stable proportion for cornering without tipping risk at this size.

# 3. Mobility Management


3.3b Printed Parts — Individual Renders (1/2)

Base | Middle plate | Top plate
Camera holder | Battery slider | N20 motor holder
N20 gear | Inner differential gear | Outer differential gear

# 3. Mobility Management


3.3b Printed Parts — Individual Renders (2/2)

Differential outer shell | Inner gear, long shaft | Inner gear, short shaft
Ring | Steering base | Steering base servo mount
Steering nut | Steering wheel mount | Wheel

# 3. Mobility Management

3.4 Mobility Measurement

To reason about how fast the car can safely go, we worked through the drivetrain's speed chain from the motor to the ground:

Wheel radius (rw):
rw = 4.7 cm / 2 = 2.35 cm = 0.0235 m

Wheel perimeter (Pw):
Pw = 2π·rw = 2 × 3.1416 × 0.0235 ≈ 0.1477 m

Motor speed and the gear reduction: ωmotor = 200 rpm (rated, no load)
ωaxle = ωmotor / 1.25 (25:20 reduction) = 160 rpm

Ground speed (theoretical, no load):
v = Pw · ωaxle = 0.1477 × 160 ≈ 23.6 m·min⁻¹
v ≈ 0.394 m·s⁻¹ (≈ 39 cm/s)

This is a ceiling, not a running speed: tyre friction, the differential, and the car's own 407 g mass all take a share of it. What actually governs how fast the car drives in competition is the 100% cruise setting in software, which cruise_speed() then eases back automatically whenever the steering is working hard — fast on the straights, deliberately slower through a turn.

# 4. Power and Sense Management

4.1 The Robot's Power Source

Power comes from three 18650 Li-ion cells in series — about 11.1 V nominal, up to 12.6 V fully charged — feeding two separate rails rather than one shared one:

The motor is wired straight from the battery to the L9110S driver's supply pin, with nothing in between. A separate DC-DC step-down converter, rated at 5 V and at least 3 A, powers the Raspberry Pi and the servo on its own rail.

This split exists because of a real failure: early on, the motor and the Pi shared one supply, and the Pi rebooted every time the motor drew current under load — a classic brownout, made worse by the driver's ground not being tied back to the Pi's ground at all, so the only electrical link between them was the GPIO signal wire itself. Separating the rails and tying every ground together (battery, driver, Pi) fixed it completely, and is now a fixed rule on the car rather than a tuning choice.

A rocker switch sits in the battery line as the master on/off. We also note, as a live watch item rather than a solved problem: a freshly charged pack at 12.6 V sits marginally above the L9110S's 12 V rating, so driver temperature is worth checking after a run.

# 4. Power and Sense Management

4.2 Main Components

- OV5647 wide-angle camera — a small-sensor, fixed-focus module with roughly a 120° field of view. It is the vehicle's only sensor: every wall, corner line, traffic sign and the parking gate is read from its image. Fixed focus means a large depth of field, so the near mat and a far wall stay sharp at the same time with nothing to hunt or mis-lock mid-run — a deliberate choice explained in the Evolution section.
- Raspberry Pi 4 Model B, 2 GB RAM, running Raspberry Pi OS Bookworm — the single board that captures every frame, runs the vision pipeline, decides the steering and speed, and drives the servo and motor through its GPIO header.
- L9110S dual H-bridge motor driver — a compact two-pin-per-motor interface, chosen for its small size and simple PWM control, sitting on its own supply rail straight from the battery.
- MG90S micro servo — ~13 g, metal gear train, powered from the Pi's 5 V rail, driving the Ackermann steering linkage.

# 4. Power and Sense Management

4.2b Why We Chose Each Component

Component | What we chose | Alternative considered | Why
Camera | OV5647 fixed-focus, wide FOV | Pi Camera Module 3 (autofocus) | Autofocus hunted and lost distant signs to blur (proof: 5.1a). A ground robot never needs to refocus, so fixed focus cost us nothing and bought a depth of field wide enough for the near mat and a far sign at once.
Motor | N20, 12 V, 200 rpm geared DC | Same footprint, higher-rpm N20 | A faster variant trades torque for speed; we needed the torque to pull the 407 g car from rest repeatedly without stalling more than we needed extra top speed.
Driver | L9110S dual H-bridge | L298N dual H-bridge | L298N's extra current headroom is wasted on a single N20 and it takes far more board space; L9110S needs only two GPIO pins and fits the chassis footprint we had.
Servo | MG90S micro servo, GPIO13 (HW-PWM) | SG90 micro servo | SG90's plastic gear train is the common failure point under repeated full-lock steering — every scripted turn and wall-emergency escape drives it to the end of travel. MG90S's metal gears take that abuse in the same footprint and mounting, for a small weight and cost increase.
Battery | 3 x 18650 Li-ion, series (~11.1 V) | 2S/3S LiPo pack | 18650 cells swap individually without a balance charger, and 11.1 V nominal clears the buck converter's dropout with margin without oversizing the pack.
Differential | Custom 3D-printed bevel differential | Solid axle (our first build) / off-the-shelf RC diff | A solid axle scrubbed the outer wheel through every corner and capped steering near 8°. An off-the-shelf diff didn't match the 25:20 gear pitch already tooled for the N20, so we designed our own.

# 4. Power and Sense Management

4.3 Wiring Diagram


# 4. Power and Sense Management

4.4 Sensing — Vision Pipeline

- Capture: the camera is read at 640x480 in RGB888, then the frame is rotated 180° in software, since the camera is physically mounted upside-down on its mast.
- Crop and resize: only the lower portion of the frame — the mat — is kept and resized down to 320x160 before any colour work happens, which both discards background clutter above the walls and keeps every frame cheap to process.
- Median blur, then HSV: a light blur is applied first because the camera runs a short exposure and elevated gain to freeze motion, which makes the raw image noisy enough to break both the colour masks and the wall scan if left untreated. The frame is then converted to HSV, which is far more stable than RGB under the mat's own lighting variation.
- Wall detection is a two-tier test, not one brightness threshold: a pixel is a wall if it is very dark regardless of colour, OR dark and low-saturation. A single brightness cut also lit up the blue and orange corner lines and the mat's printed markings, since they are dark too — and unevenly between the two frame halves, which injected a steering bias that looked like a control problem for a long time before we traced it to the measurement itself.
- Colour lines are searched only in the bottom of the region of interest, because a line painted on the mat physically cannot appear higher in the frame than the mat itself — searching the whole frame let bluish background pixels near the top trigger false line readings.

# 4. Power and Sense Management

4.4 Sensing — Camera Position

CAMERA POSITION IS CRUCIAL FOR THE ROBOT'S PERFORMANCE.

- Height 12.5 cm above the mat. The walls are 10 cm tall, so the lens must sit above the wall line to look down onto the mat and see the wall's base — the white-mat/black-wall edge, the highest-contrast feature in the frame.
- Tilt roughly 15° downward, enough to keep the mat and both wall bases in the lower frame while still seeing far enough ahead to catch a corner line or a traffic sign before reaching it.
- Centred laterally and facing dead ahead, zero yaw. Wall-following compares the left half of the frame against the right half, so any sideways offset or twist becomes a permanent steering bias that no amount of threshold tuning removes.
- Mounted on a rigid mast, not a flexible arm. A vibrating camera blurs the wall edge and injects noise straight into the steering loop, so mast stiffness is a control requirement, not a cosmetic one.
- The connection itself uses the Pi's dedicated CSI ribbon port, not a GPIO pin, so it needs no separate power and does not appear on the wiring diagram.

# 5. The Robot's Evolution

5.1 Past

Two decisions from earlier in the build turned out to be wrong in ways that only showed up once we started driving, not while designing.

The first camera was a Raspberry Pi Camera Module 3 — a larger sensor with autofocus. Focused on the mat it saw the near track sharply, but distant traffic signs blurred, and blur desaturates colour badly enough that the HSV masks lost far-away signs entirely; the car only 'saw' an obstacle once it was already close. A focus sweep confirmed we genuinely could not have both near and far sharp on that sensor at once. We replaced it with the OV5647, a smaller, fixed-focus sensor with a much larger depth of field — losing autofocus cost nothing, since a ground robot never needs to refocus.

The second was the drivetrain. Our first rear axle was solid, so both driven wheels were forced to the same speed. In a corner the outer wheel has to cover more distance than the inner one, and with no way to do that it scrubbed, losing traction and sometimes stalling the car mid-turn. Our first fix was purely in software — cutting the steering limit down step by step until the scrubbing stopped, which landed near 8°. That kept the wheels turning but left the car unable to corner tightly enough to follow the track. It was a workaround for a mechanical problem, not a fix for it.

# 5. The Robot's Evolution

5.1a Camera Decision — Proof, Not Just a Claim

Same track, same lighting, same lens height — only the camera module changed. Both frames are straight off the Pi, unedited.


BEFORE — Camera Module 3 (autofocus), focused on the near mat | AFTER — OV5647 (fixed focus), same distance and framing

The Module 3's shallow depth of field could hold either the near mat or a distant sign in focus, never both — a focus sweep across f/2.0-equivalent apertures confirmed it wasn't a tuning problem. Blur desaturates colour enough that the HSV sign masks lost far signs entirely. The OV5647's smaller sensor and fixed focus trade autofocus (never needed by a ground robot) for a depth of field wide enough to keep the whole corridor sharp at once.

# 5. The Robot's Evolution

5.1b Vision Testing — Flip & Colour Tuning


Raw sensor — mounted upside-down | After the 180° software flip | HSV Value-channel scan, tuning

The camera mounts physically upside-down on its mast, so robot.py rotates every frame 180° before anything else touches it — real capture on the left, corrected on the right.


colors.json green-sign mask, live tuning

Colour thresholds are not guessed once and left alone — colour_tuner.py runs against the live camera so every HSV band (blue line, orange line, red sign, green sign, magenta gate) is set against the real mat under the real, locked exposure. Each iteration is checked against a visible mask overlay like the one on the left, so a threshold that looks right in isolation but bleeds onto the mat itself is caught before it reaches the car.

This is the same loop that caught the sign-detection bug in the Present section: the mat/wall boundary fringe read as green at S 96-111, merging with the real sign (S 135+) into one mis-shaped blob — visible only once we started saving the mask, not from the numbers alone.

# 5. The Robot's Evolution

5.1c Vision Testing — Wall Masking & Distance Calibration


shadow_check.py — red = wall, green = free mat | freespace_test.py — gap, steer, boundary


Calibration at a taped 40 cm


Calibration at a taped 25 cm

Every distance constant in config.py traces back to frames like these: the car is placed at a taped, ruler-measured distance from the wall and freespace_test.py logs the wall-density reading at that exact spot — 40 cm measured 0.1032, 25 cm measured 0.1783 — so OUTER_TARGET is a real calibration curve, not a guessed constant. The left-hand overlay is the same diagnostic used to catch the wall-detector counting the blue/orange corner lines and the mat's own printed marks as wall (§9 of the engineering journal) — red pixels are what the code currently calls "wall".

# 5. The Robot's Evolution

5.2 Present

The current car fixes both of those at the source rather than around them.

A 3D-printed differential now sits on the rear axle, driven from the N20 motor through a 25:20 gear reduction. With the wheels free to turn at different speeds through a corner, the scrub is gone, and the steering limit came back up from 8° toward the linkage's mechanical ceiling.

The bigger present-day story, though, was perception rather than mechanics. Even after the camera swap, the car kept crashing near corners in both driving directions, in a way that no amount of gain or setpoint tuning changed. We eventually stripped the controller down to nothing and started saving an annotated frame every time the steering swung hard, colouring in every pixel the code was calling 'wall'. The answer was immediate: the wall detector was any dark pixel, and the blue line, the orange line, and the mat's own printed markings are all dark. They were being counted as wall — unevenly between the left and right halves of the frame — which is exactly why the fault only showed up near corners and resisted every attempt to tune it away. The controller had never been the problem; its input was lying to it.

Once the wall test was corrected to require genuine darkness or darkness plus low saturation, every distance constant in the project was re-measured from real centimetres, and the Open Challenge now completes in both directions with stable control.

# 5. The Robot's Evolution

5.3 Future

- Wire the parking manoeuvre into the Obstacle Challenge's main loop. The magenta gate is detected and currently treated purely as a wall to steer around; the reserved constants for the approach and stop condition already exist in config.py, but the behaviour itself is not yet connected.
- Close out a shadow-misreading issue seen at two of the four corners in field testing, where shadow on the mat is occasionally read as part of the wall. The existing two-tier wall test already rejects most shadow; a dedicated diagnostic tool (shadow_check.py) was built to separate a genuine wall from shadow in the field, and tightening the test against this case is active work.
- Move wall-following from a pure proportional-derivative law on wall distance to a heading-plus-offset controller, so the car corrects its angle to the wall rather than only its distance from it — this should make the straights noticeably straighter.
- Track a sign's position across several frames instead of frame by frame, to smooth the approach further than the current short-memory hold already does.

# 6. The Vehicle's Photos


Front | Back | Left
Right | Top | Bottom

# 7. Team

Ahmad Kalthom

Coach

Computer and Automation Engineering student, Damascus University.


Jolian Wassof

Team member

Al-Awael School. AI, robotics and drones; WRO, Pacific and Syrian AI Olympiads.

Omar Shammout

Team member

IT Engineering student, Damascus University. Robotics, AI, electronics.


Louay Rashwan

Team member

Computer and Automation Engineering student, Damascus University.

Team The Red Castle — HMK AI and Robotics Club

# 8. Links and Credits

- GitHub repository (full source, CAD, documentation):
- https://github.com/jolianjij/Red-Castle-WRO-Future-Engineers-2026
- Open Challenge driving video:
- https://youtu.be/GmrX7NhcAxE
- Obstacle Challenge driving video:
- https://youtu.be/ujbImlpQH6g

Thanks

As a team, we thank HMK AI and Robotics Club for hosting and supporting us throughout this build, and our coach, Ahmad Kalthom, for the guidance that kept the project moving through every dead end along the way.

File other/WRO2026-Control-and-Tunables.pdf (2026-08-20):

WRO 2026 Future Engineers - The Red Castle | page 1

# WRO 2026 Future Engineers — Control & Tunables

Team The Red Castle — HMK AI and Robotics Club. Generated 2026-08-20 from the programs themselves; every value below is parsed out of the source at build time, so it cannot disagree with the code.

## What the car actually measures

There is no distance sensor. Everything below is built from one 640×480 camera frame, cropped from row CROP_TOP to the bottom, taking every second column, then resized to 320×120. All pixel counts, areas and thresholds in this document live on that 320×120 frame — which is why a threshold measured on a different crop does not transfer.

crop | = raw[CROP_TOP:480, 0:640:2] | -> resize to 320x120

wall density left_wall = count(wall pixels, left half) / 12800

right_wall = count(wall pixels, right half) / 12800 The divisor is 12800 and each half is really 120×160 = 19200 pixels, so these densities are not true fractions — they run to about 1.5. That is inherited and harmless, because every target is measured on the same scale. It only matters if you compare against a number from elsewhere.

## The wall mask — what counts as a wall

wall = (V < WALL_V_HARD) OR (V < WALL_V_SOFT AND S < WALL_S_MAX)

then morphological OPEN, kernel WALL_OPEN_K

then keep only pixels in a VERTICAL RUN of >= WALL_MIN_RUN pixels
Two cases, because saturation is unreliable when V is tiny — a black wall can report S>200 from sensor noise. Testing saturation alone rejects real walls; testing brightness alone accepts the coloured lines. The vertical-run test is the shadow filter: a real wall is a tall solid run, a shadow is a broad shallow smear.

# Open Challenge — control law

One P controller on wall density. The car follows the OUTER wall: driving clockwise it turns right, so the inside of the loop is on its right and the LEFT wall is the outer one; counter-clockwise is the mirror.

direction = +1 (CW) | dir = (left_wall - CW_TARGET ) * WALL_GAIN
direction = -1 (CCW) | dir = (CCW_TARGET - right_wall) * WALL_GAIN

before the direction locks (direction = 0):

if left_wall > NEUTRAL_TARGET: dir = (left_wall - NEUTRAL_TARGET) * WALL_GAIN

if right_wall > NEUTRAL_TARGET: dir = (NEUTRAL_TARGET - right_wall) * WALL_GAIN

dir | = clamp(dir, -STEER_MAX, +STEER_MAX)

dir_servo = SERVO_SMOOTH * dir + (1 - SERVO_SMOOTH) * dir_servo_previous

pulse_us = 500 + ((dir_servo + 90 + SERVO_TRIM) / 180) * 2000
TARGET is the density a CENTRED car reads. That is the whole calibration: park it in the middle, read the number, put it here. A target that is wrong by 0.03 commands about 2° of steering while the car is already centred — a constant lean into one wall, every cycle, all run.

## Counting laps

pixels > threshold | -> state 1 (on the line)
state 1 -> below threshold | -> state 2 (crossed) -> quadrant + 1

then ignore that colour for LINE_BLANK_S seconds

12 quadrants -> keep driving FINISH_RUN_S -> stop
The count happens on the FALLING edge, so what causes a double count is the pixel count dipping below the threshold mid-crossing. A lower threshold makes that less likely, not more.

## Open Challenge tunables

tunable | now | what it does | change it when
CW_TARGET | 0.215 | Left-wall density a centred car reads, driving clockwise. | Re-measure at the venue with wall_calib.py cw. Always.
CCW_TARGET | 0.214 | Right-wall density a centred car reads, counter-clockwise. | Re-measure with wall_calib.py ccw. Should be within ~0.01 of CW_TARGET.
NEUTRAL_TARGET | 0.25 | Before the direction locks, steer away from a wall past this density. | If the car drives straight out of the start into a wall, lower it.
WALL_GAIN | 75 | Degrees of steering per unit of density error. | Raise if it corrects too slowly; lower if it weaves on a straight.
STEER_MAX | 20 | Software steering limit for ordinary driving. | Raise toward 35 if it runs wide at corners. The log prints CLAMP.
SERVO_SMOOTH | 0.35 | Exponential average on the command. 1.0 = raw. | Lower if the steering is twitchy; raise if it feels sluggish.
SERVO_DEADBAND | 0.8 | Degrees of change below which the servo pulse is not rewritten. | Raise a little if the servo buzzes while going straight.
SERVO_TRIM | -9 | Degrees added so that a command of 0 drives dead straight. | If the car curves with dir=0 in the log, adjust this, nothing else.
blue_line_threshould | 830 | Blue pixels needed to call it a line. | Set from line_audit.py blue: about 77% of a full line.
orange_line_threshould | 930 | Orange pixels needed to call it a line. | Set from line_audit.py orange.
LINE_BLANK_S | 1.2 | Seconds a colour is ignored after it is counted. | Must exceed one crossing (~0.5 s) and stay under the gap between counted lines (~5 s on a real run).
FINISH_RUN_S | 3 | Seconds of driving after the 12th quadrant. | Raise if the car stops on the line instead of past it.
CROP_TOP | 160 | First raw row kept. Lower = more wall in frame, smaller lines. | Changing this invalidates BOTH the wall targets and the line thresholds.
WALL_V_HARD | 32 | Below this brightness it is wall whatever the saturation says.
WALL_V_SOFT | 62 | Up to this brightness it is wall only if desaturated.

tunable | now | what it does | change it when
WALL_S_MAX | 90 | Saturation above this is a coloured line, not a wall.
WALL_MIN_RUN | 6 | Vertical dark pixels required to be a wall — the shadow filter. | Raise if shadow leaks in; lower if distant walls vanish.
speed | 100 | Motor PWM percent. | Lower it before you tune anything else — every threshold is easier to hit slowly.

# Obstacle Challenge — control law

Three things can steer, in this order of authority: a pillar, then a wall that is too close, then the corner kick. Between pillars there is no wall following at all — dir is 0 and the car drives straight.

## Following a pillar

d = SIGN_Y_GAIN * (119 - y) | y is the blob centre; y=0 is FURTHEST

green aim = min(320 + GREEN_TARGET_CLAMP, GREEN_NEAR_{CW|CCW} + d)

red | aim = max( | -RED_TARGET_CLAMP, | RED_NEAR | - d)
Err(green) = -(green aim - x) | pass on its LEFT -> steer LEFT
Err(red) | = (x - red aim) | pass on its RIGHT -> steer RIGHT
if green and x > 220 | : Err = 0 | (release, CW only)
if red | and x < 90 | : Err = 0 | (release, CCW only)

dir = Err * kp, clamped to GREEN_STEER_MAX or RED_STEER_MAX
The aim runs off-frame on purpose. The further away a pillar is, the further outside the 320-pixel frame the car aims, so it commits early and eases off as the pillar arrives. The clamps stop that becoming a lunge.

Measured, and still true in this build: the green release (x > 220, no distance condition) zeroes the steering on about 70% of the cycles a green pillar is held in CW, at any distance — down to x=221 with the pillar close. CCW has no such line, which is why green behaves better counter-clockwise. The distance-gated version is in git if it is wanted back.

## Walls and the corner kick

if a wall density > WALL_CLOSE: dir = +-(30 or 40) * that density

ceiling becomes WALL_STEER_MAX

corner kick, once per crossing:

CW and last sign GREEN and orange line crossed -> servo(+45)

CCW and last sign RED | and blue | line crossed -> servo(-45)

parking exit, once at the start:

purple_left > purple_right -> exit RIGHT, direction = CW (+1)

otherwise | -> exit LEFT, direction = CCW (-1)
With no purple in view at all that comparison is false, so the car silently commits to CCW. Check the first line the program prints.

## Obstacle Challenge tunables

tunable | now | what it does | change it when
kp | 0.05 | Degrees of steering per pixel of sign error. | The single strongest knob for pillar behaviour. Change it in small steps.
SIGN_Y_GAIN | 6.867 | How much further off-frame to aim per row of distance. | Raise to commit earlier to a far pillar; lower to react later.
GREEN_NEAR_CW | 300 | Where a CLOSE green pillar should sit in frame, driving CW. | Raise to pass wider around green. Try this before raising kp.
GREEN_NEAR_CCW | 262 | Same, counter-clockwise.
RED_NEAR | 120 | Where a CLOSE red pillar should sit in frame. | Lower to pass wider around red.
GREEN_TARGET_CLAMP | 400 | How far past the frame edge green may be aimed. 400 = effectively free.
RED_TARGET_CLAMP | 30 | Same for red. Small on purpose — it is what stops red lunging at the start of a section. | Raise if red is not avoided enough; lower if red over-reacts.
GREEN_STEER_MAX | 35 | Steering ceiling while following green. | Raise if green is clipped; the log shows the clamp.
RED_STEER_MAX | 15 | Steering ceiling while following red. Deliberately tighter than green. | Lower if red is still too sharp.

tunable | now | what it does | change it when
GREEN_MIN_AREA | 50 | Green blob size before it becomes a target. Area falls with the SQUARE of distance. | Keep low — green needs to start early to swing wide.
RED_MIN_AREA | 400 | Red blob size before it becomes a target. | Raise to answer red later. A pillar measures ~1220 px at mid distance.
PARALELIPIPED_MIN_AREA | 75 | Floor below which a blob is noise, not a pillar.
SIGN_MAX_ASPECT | 1 | A blob is a pillar only if width < this × height. | Raise if a CLOSE pillar is lost — its base runs off frame so its height stops growing while its width does not.
SIGN_CLOSE_AREA_CW | 500 | Area at which the sign is latched as the last one seen (CW).
SIGN_CLOSE_AREA_CCW | 1005 | Same, CCW.
WALL_CLOSE | 0.3 | Density above which a wall overrides the pillar steering. | Lower if the car touches walls; raise if it shies away from them.
WALL_STEER_MAX | 30 | Ceiling for a wall correction, so a sign's tighter limit cannot blunt it.
STEER_MAX | 30 | Ordinary steering limit when nothing special is happening.
FINISH_RUN_S | 3 | Seconds of driving after the 12th quadrant, then the car stops. The end-of-run parking search is DELETED, not disabled. | The parking EXIT at the start is a different thing and is still there — it is what chooses the lap direction.
KICK_TIME | 0.2 | Seconds the corner kick is held. It is latched, not a blocking sleep, so the vision loop keeps running through the corner.
KICK_ANGLE | 45 | Kick angle in degrees, clamped to the linkage by servo().
LINE_MIN_WIDTH | 100 | A blob must be at least this wide to count as a line.
LINE_MIN_ASPECT | 3 | And at least this many times wider than tall. Width alone is not enough — a pillar gets WIDER as the car approaches. | Measured: orange line 17.8, blue line 8.0, a cube 0.8 at ANY distance.
SIGN_DECAY_S | 2.5 | Seconds an opposite-colour sign holds before falling back to the direction's default (CW defaults GREEN, CCW defaults RED).
PILLAR_REARM_S | 0.5 | How long the target must be gone before the NEXT pillar can be recorded in the pillars list. | Stops one pillar producing fifty entries at 22 Hz.
blue_line_threshould | 750 | Blue pixels needed to call it a line. | From line_audit.py.
orange_line_threshould | 840 | Orange pixels needed. Orange shares its hue band with the RED pillars. | If phantom quadrants appear, raise this first.
LINE_BLANK_S | 1.2 | Seconds a colour is ignored after being counted.
GREEN_SAT_MIN | 150 | Green saturation floor. The MAT sits inside the green hue band, so saturation is the ONLY thing separating cube from floor. | Measured gap: mat p99=146, cube p01=157. Do not go below ~150.
GREEN_VAL_MIN | 25 | Green brightness floor. The cube is DARK — V median 38. | At 60 it kept 1% of the cube. Leave low.
RED_SAT_MIN | 120 | Red saturation floor.
PURPLE_SAT_MIN | 120 | Parking wall saturation floor.
PURPLE_VAL_MIN | 40 | Parking wall brightness floor. The wall measures V p05=52 p50=67. | Raising this loses the wall; it is what the exit direction depends on.

# Order of work at the venue

Do these in order. Each step assumes the ones above it are already right; doing them out of order means measuring through a mistake.

# | step | tool | why

1 | Lock the camera | mask_debug.py | Look at the picture before any number. If the walls are not dark and the lines are not solid, nothing measured afterwards means anything. Venue lighting is the biggest single change between practice and competition.
2 | Walls, both directions | wall_calib.py cw then ccw | Park CENTRED, read the density, put it in CW_TARGET / CCW_TARGET. The two should agree within about 0.01 — if they do not, the car was not centred for one of them.
3 | Lines | line_audit.py blue / orange | Park over each line. Set the threshold near 77% of a full line. Check the frame-to-frame spread does not straddle it.
4 | Pillars | sign_calib.py | Green and red at equal distance should give equal area and equal y. If one is much smaller, its colour range is clipping the cube — fix that before touching kp.
5 | Parking walls | park_calib.py | Only for the obstacle start. Check both purple counts and that one side clearly wins — a near tie means a coin toss for the lap direction.
6 Drive, then read the | log | logs/*.csv | Every run writes its own timestamped file. Do not tune from memory of what the car looked like; the log has the wall densities, the pixel counts, the target and the steering before and after the clamp.

## Three rules that have cost this car whole runs

1. A threshold belongs to the crop it was measured on. CROP_TOP was raised from 240 to 160 to get the walls in frame, which squashes 320 rows into 120 instead of 240 into 120. Lines are horizontal, so they lose pixels in proportion: the same frame gives 1421 px of blue through the old crop and 1077 through this one. Both line thresholds were silently too high for months because of it.
2. Brightness floors set on a brighter camera reject the object. The same mistake three times: orange needed V>125 where the line reads 78; blue needed V>70 where it reads 43; green needed V>60 where the cube reads 38 and only 1% of it survived. If something is not detected, check the V floor before anything else.
3. A controller commanding zero looks exactly like a controller that is happy. The neutral wall target was 0.5 on a camera whose densities reach 0.25, so before the direction locked the car steered nothing at all and drove straight out of the start into the wall. Read dir in the log, not the car.

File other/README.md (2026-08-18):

# other — documentation

**Start here:** [`start-here.html`](start-here.html) — the hub. Which document
answers which question, the five commands you actually use, and where the
project stands.

| file | what it answers |
|---|---|
| [`start-here.html`](start-here.html) | *Where do I even begin?* |
| [`system-reference.html`](system-reference.html) | *How does the car actually work?* |
| [`tunables.html`](tunables.html) | *It is misbehaving — what do I change?* |
| [`api-reference.html`](api-reference.html) | *What can I call in my own code?* |
| [`code-walkthrough.html`](code-walkthrough.html) | *Why is this line here?* |
| [`tuning-strategy.md`](tuning-strategy.md) | *What do I do at the venue, in what order?* |
| [`ssh-commands.md`](ssh-commands.md) | *How do I copy that to the Pi?* |
| [`venue-setup.md`](venue-setup.md) | *No wireless allowed — now what?* |
| [`bill-of-materials.md`](bill-of-materials.md) | what the car is made of |
| [`wro-requirements-compliance.md`](wro-requirements-compliance.md) | the rules, and where we meet them |

The four HTML documents are also published as web pages — the links are in
`start-here.html`.

## Regenerating

Three of them are generated from `src/`, so they cannot drift from the code.
**Regenerate rather than editing them by hand:**

```bash
python other/build-api-reference.py      # api-reference.html
python other/build-tunables.py           # tunables.html
python other/build-code-walkthrough.py   # code-walkthrough.html
```

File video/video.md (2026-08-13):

# video — driving demonstration

## Official requirement (WRO 2026 General Rules, §7)

> URL to YouTube (should be either public or accessible by link) showing the
> vehicle driving autonomously. That part of the video where driving
> demonstration exists, must be **at least 30 seconds** in length.
> **One video for each challenge** must be provided.

| Requirement | Detail |
|---|---|
| Platform | **YouTube** (public, or unlisted/accessible by link) |
| Length | the driving demonstration itself must be **≥ 30 seconds** |
| Count | **two videos** — one for the Open Challenge, one for the Obstacle Challenge |
| Content | the vehicle driving **autonomously** (no remote control, no human intervention) |

## Our videos

- **Open Challenge:** https://youtu.be/GmrX7NhcAxE
- **Obstacle Challenge:** https://youtu.be/ujbImlpQH6g

## Filming checklist

- [x] Record the **full run** — from the start signal to the finish/park.
- [x] Keep at least **30 seconds of continuous driving** in frame.
- [x] Show the whole track so judges can see the vehicle stays inside the walls.
- [x] Make it obvious the run is autonomous (hands visible and away after the start).
- [x] Upload as **public or unlisted**, then paste the links above.
- [x] Verify the links open in a private/incognito window before submitting.

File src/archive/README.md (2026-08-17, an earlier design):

# archive — superseded diagnostic programs

These are **not used in competition**. They are kept because the engineering
journal cites the measurements they produced, and each one settled a question
that changed the design.

| File | What it was for | What it proved |
|---|---|---|
| `legacy_open.py` | Last year's Open Challenge code, ported to this year's hardware | Their constants do **not** transfer. Their wall target of 0.5 read **0.021** on our camera — different lens, different mounting height, different ROI. This is why every distance constant was re-measured on this car instead of copied. |
| `pure_open.py` | The single-wall control law and nothing else — no emergency, no corner code, no lap counting | That corners are handled **implicitly**: approaching one, the wall ahead raises the outer-wall density, which drives the steering into the turn. No dedicated corner detector is needed for the law to work. |
| `freespace_test.py` | Visualiser for the free-space / follow-the-gap profile ("method B") | The gap follower was built and measured, then **rejected**: it skipped the wall emergency, and 79 of 98 near-collision frames had zero avoidance. The outer-wall PD replaced it. |

The live programs are `src/open_challenge.py` and `src/obstacle_challenge.py`.

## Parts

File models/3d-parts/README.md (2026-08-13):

# 3D Parts — source CAD

Individual printable parts, exported as STL, one folder per subassembly.
`Mechanical-BOM.docx` is the authoritative parts list (quantities, moving/fixed,
material) — reproduced as a table in [`../README.md`](../README.md).

```
3d-parts/
├── chassis/                     base plate, middle plate, top plate, camera holder
├── steering/                    Ackermann linkage — base, servo mount, ring, nut, wheel mounts
├── rear-drive/                  differential, gears, N20 motor holder
├── wheels/                      wheel + shaft mount
├── battery-slider-mechanism/    battery tray, sliding part
└── Mechanical-BOM.docx          source bill of materials
```

Individual per-part renders (17 of 20, used as the BOM photo column) are in
[`../renders/parts/`](../renders/parts) and shown in the BOM table in
[`../README.md`](../README.md#bill-of-materials--3d-printed-parts).

> **Still to add:** the full Fusion 360 robot assembly file (`.f3d` / `.step`),
> the differential + steering assembly-with-pictures notes, and renders for
> the last 2 parts (battery slider p2, wheel-mount-to-shaft).

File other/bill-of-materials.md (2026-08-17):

# Bill of Materials — Team The Red Castle (WRO 2026 Future Engineers)

## Electronics — compute & sensing
| # | Component | Spec / notes | Qty |
|---|---|---|---|
| 1 | Raspberry Pi 4 Model B | **2 GB RAM**; Raspberry Pi OS Bookworm 64-bit | 1 |
| 2 | microSD card | 16–32 GB, A1/A2, with Bookworm flashed | 1 |
| 3 | **OV5647 wide-angle camera** | 5 MP, ~120° FOV, **fixed focus** (deep depth of field) — the only sensor | 1 |
| 4 | CSI camera ribbon cable | Pi 4 CSI port → camera on the mast (~15 cm); carries data **and** power | 1 |

## Electronics — actuation & motor driver
| # | Component | Spec / notes | Qty |
|---|---|---|---|
| 5 | **L9110S** dual H-bridge module | drives the DC motor; `A-IA`→GPIO24, `A-IB`→GPIO23; rated 2.5–12 V, ~0.8 A | 1 |
| 6 | **N20 gear motor** | 12 V, **200 rpm**, brushed micro gear motor — rear-axle drive | 1 |
| 6a | **Differential** | rear axle differential — lets the driven wheels turn at different speeds | 1 |
| 6b | Transmission gears | **25:20** spur pair (1.25:1 reduction), motor pinion → differential | 1 set |
| 7 | **MG90S** steering servo | ~13 g metal-gear micro servo; signal → GPIO13, powered from the Pi's 5 V | 1 |
| 8 | Drive wheels + tires | rear, on the differential axle, **4.7 cm** diameter | 2 |
| 9 | Steering wheels (front) + Ackermann linkage | 3D-printed knuckles + tie-rod + servo horn | 1 set |

## Power
| # | Component | Spec / notes | Qty |
|---|---|---|---|
| 10 | **18650 Li-ion cells** | **3 in series** (~11.1 V nominal, 12.6 V full); feeds L9110S `VCC` directly | 3 |
| 11 | 3× 18650 battery holder | series holder with leads | 1 |
| 12 | **DC-DC step-down (buck) converter** | adjustable, set to **5 V**, ≥ 3 A — dedicated to the Pi (separate rail) | 1 |
| 13 | Rocker power switch | master on/off in the battery line | 1 |
| 14 | Screw terminal blocks | 2-pin, for the battery/power distribution joints | 2–3 |
| 15 | Smoothing capacitor | ~1000 µF across L9110S `VCC`–`GND` (recommended) | 1 |
| 16 | Push button | start / emergency-stop button → **GPIO19** and GND. Uses the Pi's internal pull-up, so no resistor is needed. | 1 |

## Wiring & fasteners
| # | Component | Spec / notes | Qty |
|---|---|---|---|
| 17 | Jumper wires (M-F, F-F) | signal + power; **common ground** Pi↔driver↔battery | pack |
| 18 | Heat-shrink / connectors | tidy the power joints | as needed |
| 19 | M3 × 8 mm screws | mounting the printed chassis parts | 18 |
| 20 | M3 × 20 mm screws | mounting the printed chassis parts | 4 |
| 21 | Brass standoff, male–female, 25 mm | Pi mounting stack | 4 |
| 22 | Brass standoff, female–female, 20 mm | Pi mounting stack | 4 |

## 3D-printed parts

20 printed parts across 5 subassemblies (chassis, steering, rear drive/differential,
wheels, battery slider) — full quantities, fixed/moving status and source files
are in **[`../models/README.md`](../models/README.md)**. All parts are PLA+.

## Tools (not shipped, but needed to build)
- 3D printer + filament (PLA/PETG)
- Soldering iron + solder
- Screwdrivers, hex keys, pliers/cutters
- **Multimeter** (verify VCC, common ground, motor voltage)
- The WRO game mat + field walls for testing

---
## Manufacturing
| Item | Detail |
|---|---|
| CAD | **Fusion 360** — full assembly + parts in [`../models/`](../models) |
| 3D printer | **Bambu Lab A1** |
| Material | **PLA+ Silk Silver** |
| Sliced plates | print-ready plates with settings in [`../models/printing/`](../models/printing) |

## Total build cost

**≈ $120**, electronics, printed parts (filament), fasteners and battery combined.

### Power note
Three 18650 cells in series give ~11.1 V nominal (12.6 V fully charged). The
L9110S is rated **2.5–12 V**, so a freshly charged pack sits marginally above its
maximum — keep an eye on driver temperature. The motor sees the pack voltage minus
the L9110S's internal drop (~1.5–1.8 V). Full wiring: [`../schemes/`](../schemes).

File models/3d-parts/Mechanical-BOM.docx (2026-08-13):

# BOM:

Part name: | Quantity: | Image: | Fixed/Moving: | Material:
Base | 1 | | FIxed | Pla+
Middle plate | 1 | | FIxed | Pla+
Top plate | 1 | | Fixed | Pla+
Camera holder | 1 | | Fixed | Pla+
Battery slider p1 | 1 | | Fixed | Pla+
Battery slider p2 | 1 | | Moving | Pla+
N20 holder | 1 | | Fixed | Pla+
N20 gear | 1 | | Moving | Pla+
Inner Differential gear | 2 | | Moving | Pla+
Outer Differential gear | 1 | | Moving | Pla+
Differential outer shell | 1 | | Fixed | Pla+
Inner gear with long shaft | 1 | | Moving | Pla+
Inner gear with short shaft | 1 | | Moving | Pla+
Ring | 2 | | Moving | Pla+
Steering base | 1 | | Moving | Pla+
Steering base servo mount | 1 | | Moving | Pla+
Steering nut | 2 | | Moving | Pla+
Steering wheel mount | 2 | | Moving | Pla+
Wheel | 4 | | Moving | Pla+
Wheel mount to shaft | 4 | | Moving | Pla+

Note: Moving parts need lubrication to reduce friction I recommend using Vaseline.

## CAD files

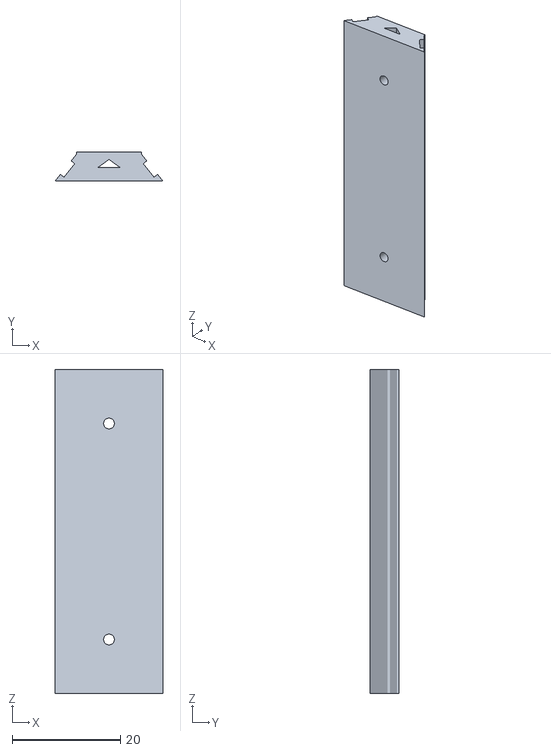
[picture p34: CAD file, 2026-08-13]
models/3d-parts/battery-slider-mechanism/battery slider p1.stl
20.0 x 5.40 x 60.0

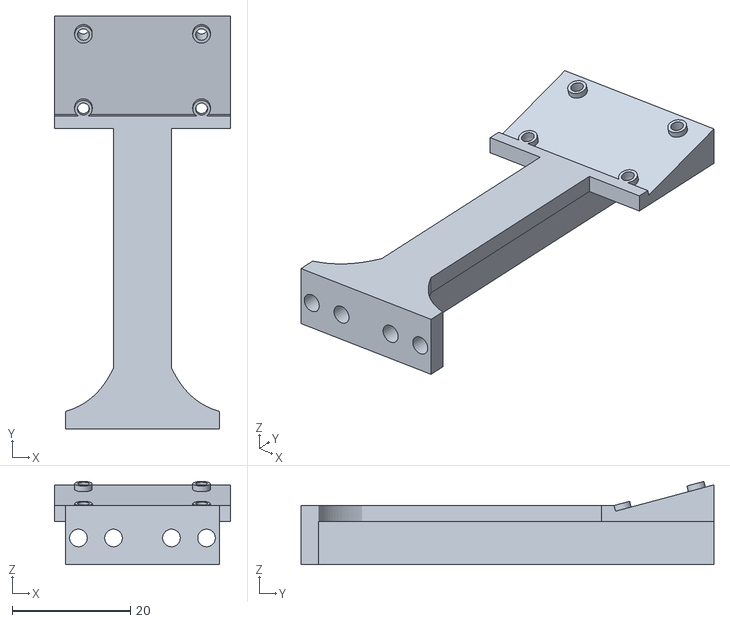
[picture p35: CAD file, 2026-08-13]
models/3d-parts/chassis/Camera holder.stl
29.8 x 69.9 x 14.1

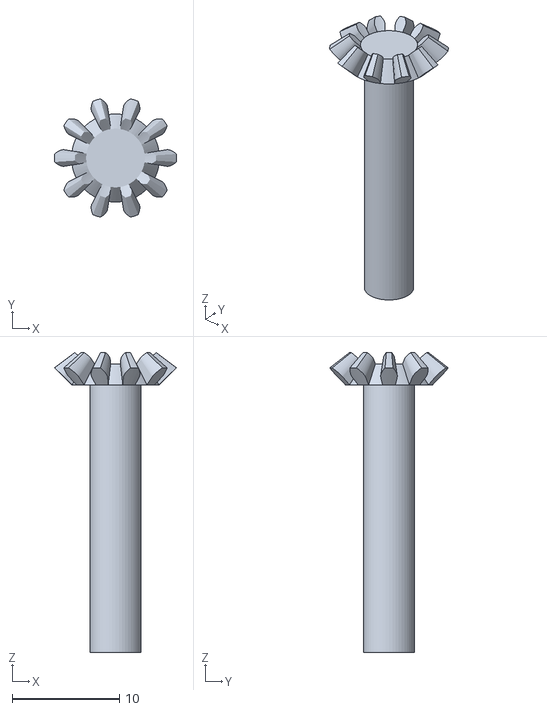
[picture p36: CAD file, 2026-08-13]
models/3d-parts/rear-drive/inner difrentail gear(long shaft).stl
11.4 x 11.1 x 28.0

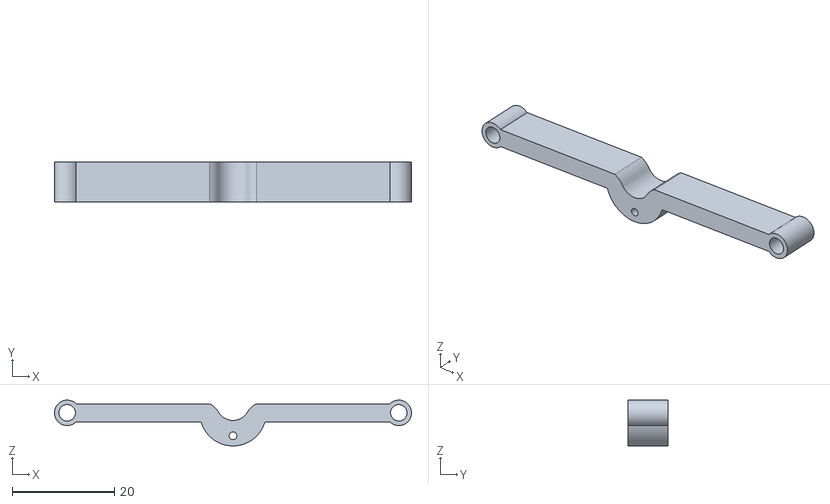
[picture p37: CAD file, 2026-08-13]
models/3d-parts/steering/steering base servo_.stl
70.0 x 7.80 x 8.99

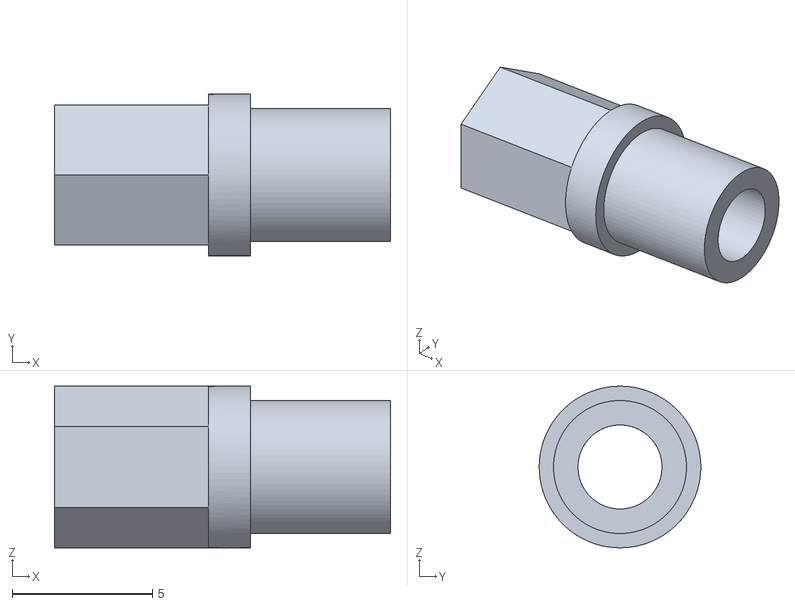
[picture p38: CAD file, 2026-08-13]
models/3d-parts/wheels/wheel mount to shaft.stl
12.0 x 5.77 x 5.77

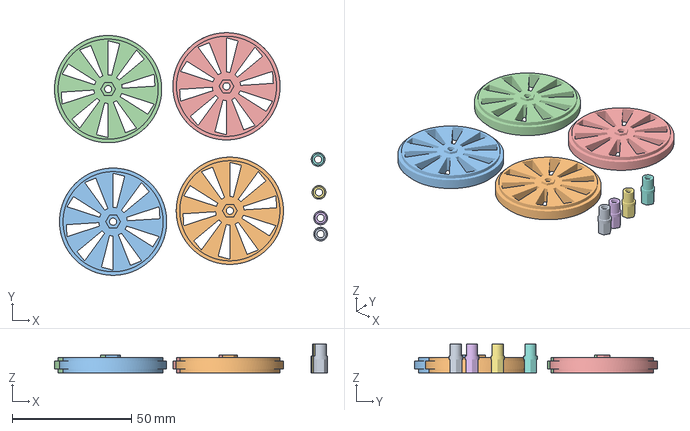
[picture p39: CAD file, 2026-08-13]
models/printing/wheels-ready-to-print.3mf
114.5 x 101.8 x 12.0 mm
wheel mount to shaft.stl x 4
wheel.stl x 4

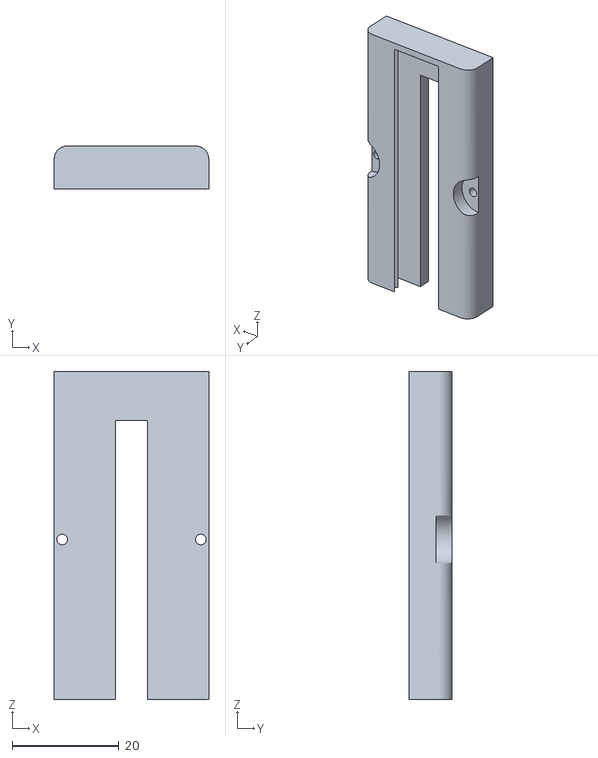
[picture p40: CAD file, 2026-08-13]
models/3d-parts/battery-slider-mechanism/battery slider p2.stl
29.0 x 8.10 x 61.5

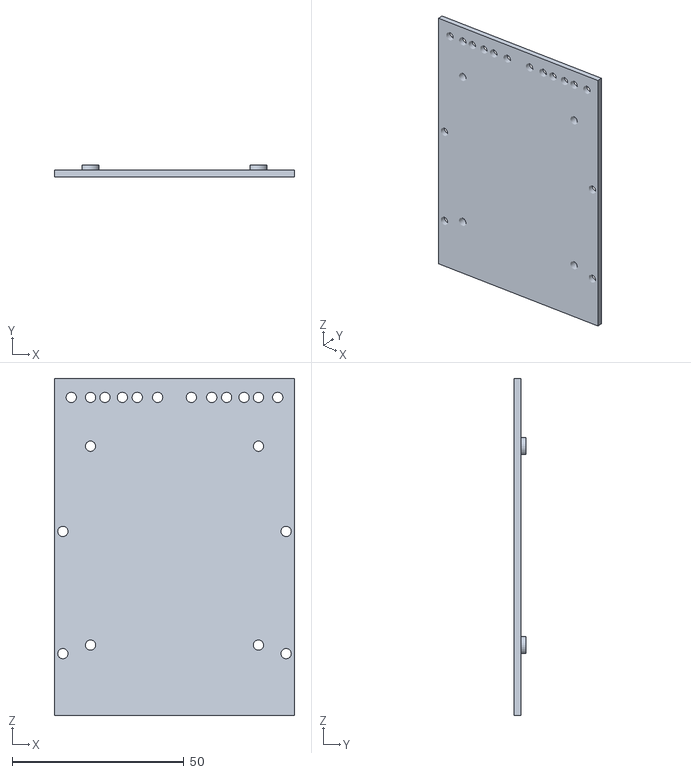
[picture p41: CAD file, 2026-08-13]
models/3d-parts/chassis/midle plate.stl
70.0 x 3.50 x 98.1

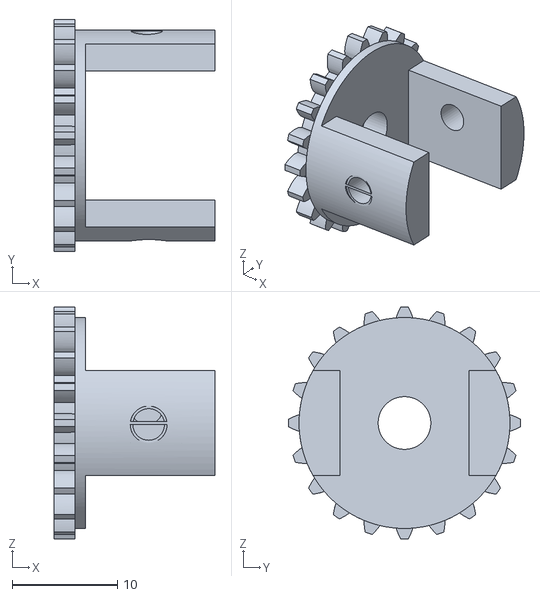
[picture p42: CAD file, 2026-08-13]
models/3d-parts/rear-drive/diffrentail outergear.stl
15.3 x 22.0 x 22.0

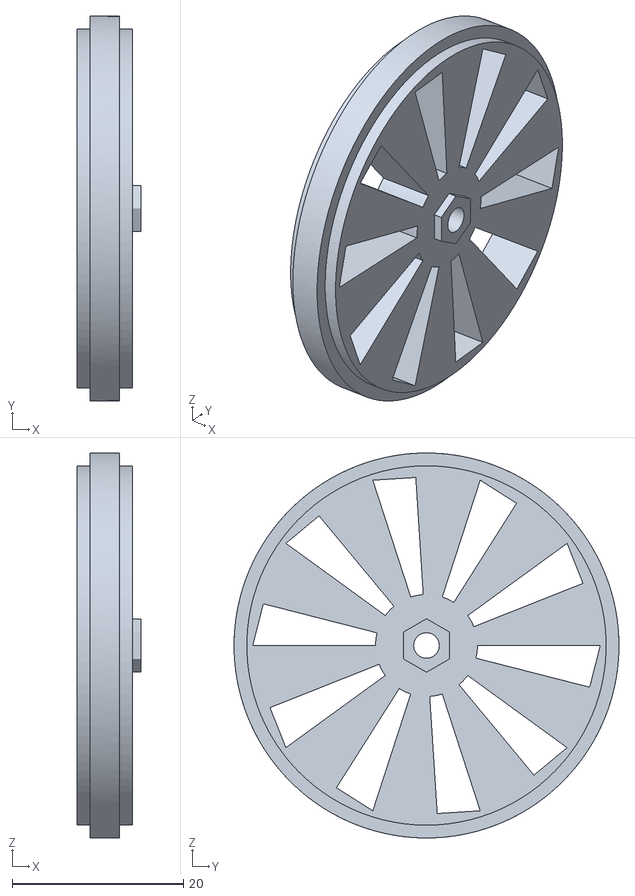
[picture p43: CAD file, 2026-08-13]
models/3d-parts/wheels/wheel.stl
7.50 x 45.0 x 45.0

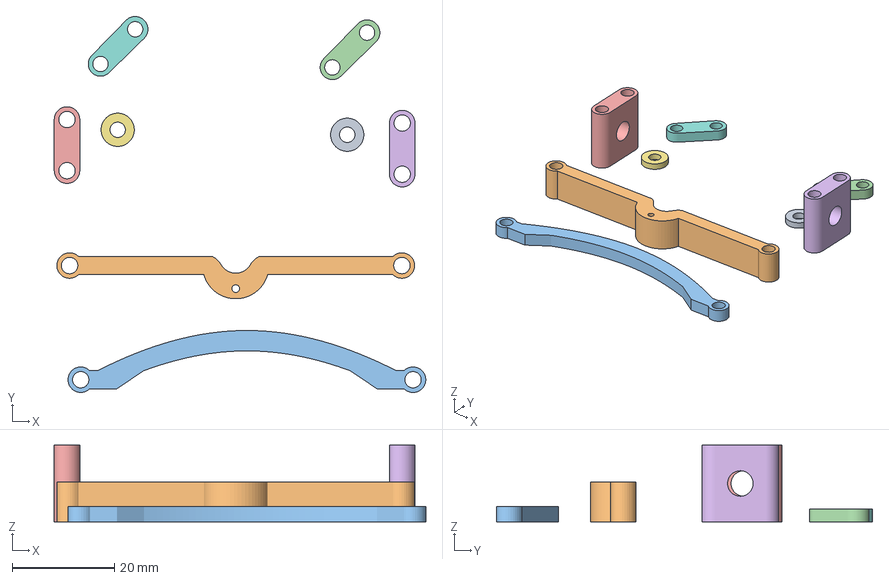
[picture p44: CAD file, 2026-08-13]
models/printing/steering-ready-to-print.3mf
72.7 x 73.5 x 15.0 mm
Ring.stl x 2
steering base servo_.stl
steering base.stl
steering nut.stl x 2
steering wheel mount.stl x 2

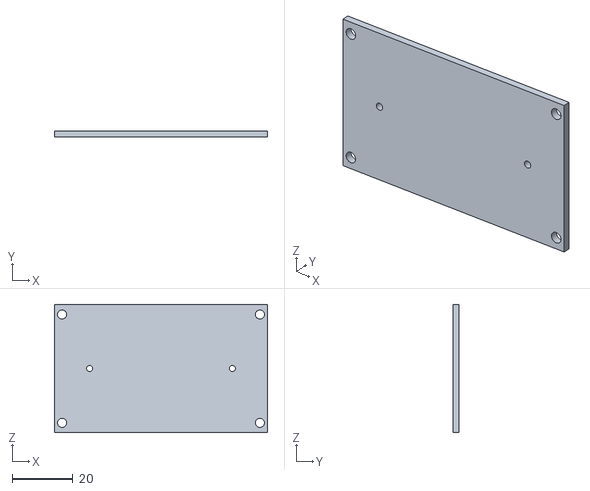
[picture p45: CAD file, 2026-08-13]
models/3d-parts/chassis/top plate.stl
70.0 x 2.00 x 42.2

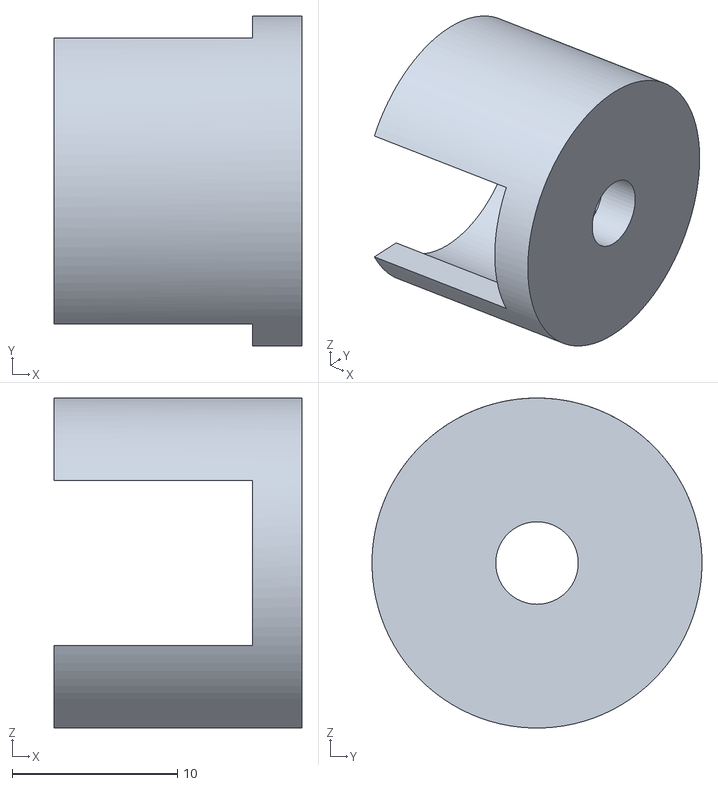
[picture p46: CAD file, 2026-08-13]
models/3d-parts/rear-drive/diffrentail shell.stl
15.0 x 20.0 x 20.0

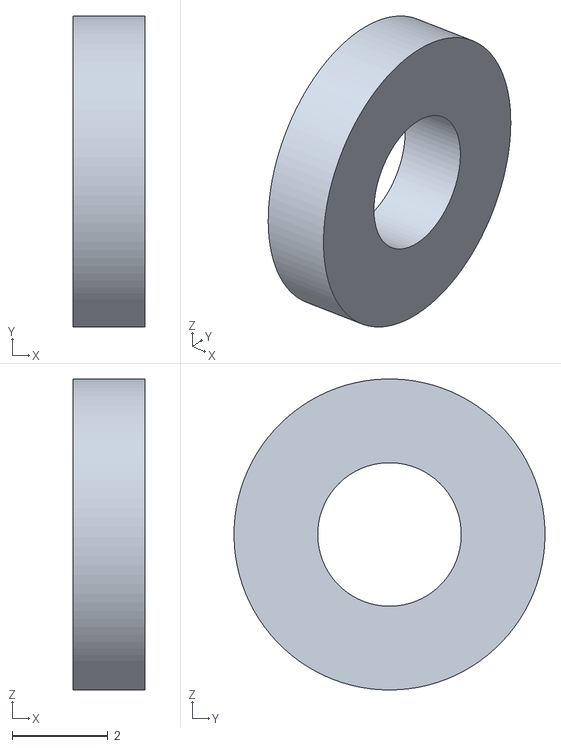
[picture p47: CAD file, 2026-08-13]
models/3d-parts/steering/Ring.stl
1.50 x 6.50 x 6.50

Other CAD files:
models/printing/chasis-ready-to-print.3mf
models/3d-parts/chassis/base.stl
models/3d-parts/rear-drive/small difrentail gear.stl
models/3d-parts/steering/steering base.stl
models/3d-parts/rear-drive/N20 motor holder.stl
models/3d-parts/rear-drive/inner difrentail gear(short shaft).stl
models/3d-parts/rear-drive/n20 gear.stl
models/3d-parts/steering/steering nut.stl
models/3d-parts/steering/steering wheel mount.stl
models/printing/battery slider-ready-to-print.3mf
models/printing/rear-drive-ready-to-print.3mf

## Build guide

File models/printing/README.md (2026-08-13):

# Printing — sliced, ready-to-print files

Five pre-sliced **3MF** plates (Bambu Studio), one per subassembly, each
containing every part of that subassembly arranged and sliced for the
**Bambu Lab A1** in **PLA+ Silk Silver**:

| File | Subassembly |
|---|---|
| `chasis-ready-to-print.3mf` | base plate, middle plate, top plate, camera holder |
| `steering-ready-to-print.3mf` | Ackermann steering linkage |
| `rear-drive-ready-to-print.3mf` | differential, gears, N20 motor holder |
| `wheels-ready-to-print.3mf` | wheels + shaft mounts |
| `battery slider-ready-to-print.3mf` | battery tray + slider |

Open a `.3mf` directly in Bambu Studio — it carries the plate layout and print
settings, so it reproduces the exact print used for the competition robot.
Source STLs for each individual part are in [`../3d-parts/`](../3d-parts).

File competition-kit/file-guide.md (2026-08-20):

# Every file, what it is, and when to use it

Two things to know before the list:

**There are two generations of code here.** The `robot.py` library came first;
the two ported programs replaced it. Both are still on disk. A tool built
against `robot.py` reads **different constants** from the ones the car actually
runs on, so its numbers do **not** transfer. Each tool below says which
generation it belongs to.

**Run everything from `~/wro2026` on the Pi**, with the venv active:

```bash
cd ~/wro2026 && source .venv/bin/activate
```

---

# The two programs

These are what drive the car. Nothing else does.

| file | what it is |
|---|---|
| **`open_challenge.py`** | Three laps, no obstacles. Follows one wall at a measured density target, counts quadrants off the lines, stops 3 s after the twelfth. |
| **`obstacle_challenge.py`** | Three laps avoiding red and green pillars. Leaves the parking lot, chooses its lap direction from which side has more magenta, steers around pillars, stops 3 s after the twelfth quadrant. Parking at the end is **deleted**. |

```bash
python open_challenge.py
python obstacle_challenge.py
```

Both wait for the **button on GPIO19** before anything moves, and the same
button is the emergency stop. Both print their whole configuration at startup
and one full line per cycle, and both write `logs/<name>_<timestamp>.csv` — a
new file per run, so a bad run is never overwritten by the next one.

### The old library — still on disk, no longer driving

| file | status |
|---|---|
| `robot.py`, `config.py`, `camera.py` | **LEGACY.** The pre-port library. Its constants are *not* the ones the car runs on. Kept because several tools still import it. |

---

# Tuning tools — the current generation

These import the ported programs and use their **real** crop, camera locks and
masks, so a number measured here means the same thing as a number inside the
program. **These are the ones to use.**

### `wall_calib.py` — the wall-following targets

```bash
python tools/wall_calib.py cw 30      # then flip the car and run ccw
```

Park the car **centred** between the walls. Reports the wall density each side
and tells you what `CW_TARGET` / `CCW_TARGET` should be — because a centred car
should be commanded to steer **zero**, so the target *is* the centred density.

*The check that matters:* a centred car must read left and right within about
0.01 of each other. If they differ by 0.05 the car is not actually centred, and
the target you take from it will lean the car into a wall for the whole run.

### `sign_calib.py` — pillar detection and the steering law

```bash
python tools/sign_calib.py 15
```

Put a **green and a red cube at equal distance** and run it. Reports each one's
area, centre, box and whether it is accepted as a sign, then what the steering
law would command for each.

*The check that matters:* at equal distance the two must report **the same area
and the same y**. Before the green fix they were 10 px against 1222; after,
1279 against 1218.

### `line_audit.py` — why a line's pixel count is what it is

```bash
python tools/line_audit.py blue
python tools/line_audit.py orange
```

For **each bound separately**, counts the pixels that pass every *other* bound
and fail only that one. That is how you find which threshold is wrong instead of
guessing. Also measures what the crop costs, and warns if the threshold sits
inside the frame-to-frame spread — which is what makes a line flicker and get
counted twice.

### `park_calib.py` — the parking walls and the exit direction

```bash
python tools/park_calib.py 15
```

Car in the **start box**, exactly as it will start. Reports purple left vs
right, which direction that chooses, and whether the mask is getting the whole
wall.

*It flags two silent failures:* no purple at all (the comparison is `False`, so
the car quietly commits to CCW) and the two sides being too close (a little
noise then flips your lap direction).

### `hsv_pick.py` — get NEW HSV bounds at the venue

```bash
python tools/hsv_pick.py green
python tools/hsv_pick.py red --wrap
```

The others *check* bounds you have; this one **proposes** new ones from what the
object measures under the venue's light. Prints lines to paste in, then
re-counts with them and reports how much of the rest of the frame they let in.

### `color_count.py` — pixel count for any HSV range

Both a tool and an importable function — this is the one for the **surprise
challenge**.

```bash
python tools/color_count.py 90 135 140 255 20 200 --name blue
```

```python
from color_count import color_count, color_count_halves, color_blob
n = color_count(hsv, h=(35, 85), s=(120, 255), v=(40, 255))
```

`color_count_halves()` gives left/right for side decisions; `color_blob()` gives
shape, because a pixel count cannot tell a solid object from speckle. Hue wrap
is handled for red-like ranges.

### `mask_debug.py` — see every mask at once

```bash
python tools/mask_debug.py
```

Renders the camera view with each colour mask overlaid, so you can *see* what is
matching rather than infer it from counts.

### `servo_jitter.py` — is the steering noise the code or the pulse?

```bash
python tools/servo_jitter.py
```

Front wheels hanging free. Holds **one constant angle** three ways —
`RPi.GPIO` held, `RPi.GPIO` released, `pigpio` DMA-timed — six seconds each. The
command never changes inside a phase, so anything that moves is not the control
loop. This is what proved the buzzing was software PWM.

---

# Tests — no car needed

Run these on the laptop after any edit.

| file | what it proves |
|---|---|
| **`test_obstacle_run.py`** | Actually **runs** `cycle()` across seventeen states — both directions, each cube, each line, the parking wall, quadrants 11/12/13, a live kick and an expired one — and checks the run really stops 3 s after the twelfth quadrant. Catches what a compile check cannot. |
| **`test_pillars.py`** | Nine checks on the pillar recorder and the sign decay: one pillar gives one entry, a different colour interrupts, a short dropout does not re-arm, the decay flips once and settles. |
| `test_logic.py` | **LEGACY.** Tests `robot.py`, the corner kick, the button and the steering limits. Stops cleanly at the pre-port boundary and says so. |

---

# Workflow scripts

| file | use |
|---|---|
| **`sync.sh`** | `./sync.sh push` copies the laptop's code to the Pi. **It overwrites what is on the Pi** — check first if you have tuned there. |
| **`backup.sh`** | `./backup.sh save` pulls a full snapshot from the Pi into `backups/`. Run before changing anything. |
| `src/run.sh` | What autostart runs. The `PROGRAM=` line picks which challenge. |
| `src/autostart.sh` | `on` / `off` / `status`. Installs the systemd unit that runs the car at boot. It waits for `pigpiod`, because without it the servo silently falls back to software PWM and buzzes. |
| `src/tools/venue_net.sh` | `status` / `wifi-off` / `wifi-on` on the Pi. `wifi-off` refuses unless the laptop has actually taken an address and answers a ping. |

---

# Documents

| file | what it answers |
|---|---|
| **`color-tuning-strategy.md`** | Every colour, one at a time — what it decides, its measured H/S/V, what breaks it, and the command to check it. Plus the venue procedure and the collision map. **Read this before touching any threshold.** |
| **`file-guide.md`** | This file. |
| **`moving-files-scp.md`** | Copying files both ways with `scp`, and the gotchas that have actually bitten us. |
| `new-laptop-setup.md` | Setting up a second laptop on the Pi's Ethernet cable. |
| `venue-setup.md` | Wired networking, radios off, and recalibrating for the venue's light. |
| `ssh-commands.md` | The commands used most often, ready to paste. |
| `tuning-strategy.md` | The older, driving-focused strategy: what to do at the venue in order, and what to change when it hits walls or mishandles signs. |
| `rules-and-mission.md`, `wro-requirements-compliance.md`, `bill-of-materials.md` | The competition rules, how this robot meets them, and the parts list. |
| `start-here.html` and the other HTML | Generated reference pages — open in a browser. |

---

# Older tools, kept but superseded

All of these were written against **`robot.py`**, so their numbers do not match
what the car now runs. Use the current-generation equivalent instead.

| old tool | use instead |
|---|---|
| `tune_colors.py`, `color_tuner.py` | `hsv_pick.py`, `color_count.py` |
| `tune_walls.py` | `wall_calib.py` |
| `line_check.py`, `line_calib.py` | `line_audit.py` |
| `park_check.py` | `park_calib.py` |
| `shadow_check.py` | `wall_calib.py` (it shows the shadow mask directly) |
| `symmetry_check.py`, `outer_test.py`, `dryrun.py` | `test_obstacle_run.py` |
| `video_colors.py` | `hsv_pick.py` on the real field |

Small standalone hardware checks, still fine to use:

| tool | use |
|---|---|
| `servo_center.py` | find the steering trim |
| `motor_debug.py`, `motor_speed_steps.py` | motor direction and speed |
| `button_test.py` | prove the button reads |
| `preview.py`, `cam_capture.py`, `mjpeg_stream.py` | look through the camera |
| `driver_on.py` | power the motor driver |

---

# The order to use them in at the venue

1. `backup.sh save` — before touching anything.
2. `wall_calib.py cw` and `ccw` — if the densities are near 0.215 a side, the light has not moved and you may need nothing else.
3. `line_audit.py blue` and `orange` — the lines, if a lap is miscounted.
4. `sign_calib.py` — the cubes, if a pillar is mishandled.
5. `park_calib.py` — the start box, before the first obstacle run.
6. `hsv_pick.py <colour>` — only if something is genuinely **missed**, and check its brightness floor first.
7. `test_obstacle_run.py` on the laptop after any edit.

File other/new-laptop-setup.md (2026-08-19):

# Setting up a SECOND laptop on the Pi's Ethernet cable

The Pi is already configured and needs **nothing changed**. `eth0` runs in
NetworkManager *shared* mode: the Pi holds a fixed address and runs its own
DHCP server on that cable.

| | |
|---|---|
| Pi | `192.168.50.1` — fixed, always there |
| Laptop | `192.168.50.10`–`254` — handed out by the Pi |
| Cable | any normal patch cable (Pi 4 Ethernet is auto-MDIX, no crossover needed) |

So the second laptop needs its wired adapter on **"Obtain an IP address
automatically"**, which is the Windows default. Plug in, wait ~5 seconds, done.

---

## Do this BEFORE the venue, not at it

At the venue there is no internet and no wireless. Everything below that needs
a download must happen while you still have a connection.

### 1. Check the laptop actually has a working Ethernet port

This is the step that failed on the first laptop — the hardware was present but
Windows had no driver for it (`Code 45`, adapter absent from Settings).

```powershell
Get-NetAdapter | Format-Table Name, InterfaceDescription, Status, LinkSpeed
```

You want a row that is clearly a wired NIC (Realtek / Intel / "Ethernet") with
`Status` of `Up` or `Disconnected`. **`Disconnected` is fine** — that just means
no cable. If no wired row appears at all, that laptop cannot do this either, and
a USB-to-Ethernet adapter is the fix (buy one that works without a driver
download, or install its driver in advance).

### 2. Confirm the SSH client is installed

Windows 10/11 ship OpenSSH, but it can be absent on trimmed installs.

```powershell
Get-Command ssh
```

If missing:

```powershell
Add-WindowsCapability -Online -Name OpenSSH.Client~~~~0.0.1.0
```

### 3. Install a VNC viewer, if you want the desktop

RealVNC Viewer. Download it now. You connect to `raspberrypi:5900` once the
hosts entry below is in place (or `192.168.50.1:5900`).

### 4. Clone the repository

You will want the code, the tools and the docs on this machine too.

```bash
git clone https://github.com/jolianjij/Red-Castle-WRO-Future-Engineers-2026.git
```

Do this now — at the venue you cannot.

### 5. Make the bare hostname `raspberrypi` work

**MEASURED on this laptop, and it is the opposite of what you would expect:**

```
raspberrypi        -> WORKS    (Windows ICS DNS, while on the hotspot)
raspberrypi.local  -> FAILS    (Git Bash does not do mDNS here)
```

So do not rely on `.local`. Windows' own resolver handles it in PowerShell, but
the Git Bash `ssh` that every tool in this repo uses does not, on this machine.

Over a direct cable there is no DNS server at all and no search domain to append
`.local` for you, so neither name resolves on its own. Because the Pi's address
on that cable is fixed at `192.168.50.1`, one hosts-file line fixes it
permanently:

Open PowerShell **as Administrator**:

```powershell
Add-Content -Path C:\Windows\System32\drivers\etc\hosts -Value "`n192.168.50.1`traspberrypi" -Encoding utf8
```

Then `ssh pi@raspberrypi` works, with no `.local` and no address typed.

> **This entry is for the CABLE, and it breaks Wi-Fi access.** It is safe to
> hard-code only because the Pi's wired address is static. On the hotspot the Pi
> has a different address (192.168.137.x), and this entry would send you to
> 192.168.50.1, which is not reachable without the cable.
>
> So: **add it at the venue, remove it at home.** The script does both:
> `-AddHostsEntry` and `-RemoveHostsEntry`.
>
> At home on the hotspot you do not need it - the bare name already works there
> through Windows' own DNS.

---

## Connecting

```bash
ssh pi@raspberrypi
```

Password, or copy your key across:

```powershell
type $env:USERPROFILE\.ssh\id_ed25519.pub | ssh pi@raspberrypi "mkdir -p ~/.ssh && cat >> ~/.ssh/authorized_keys"
```

If you have no key on the new laptop yet:

```powershell
ssh-keygen -t ed25519
```

---

## What "working" looks like

```powershell
ipconfig | Select-String -Context 4 "Ethernet"
```

The wired adapter should show an address of `192.168.50.x`. **Windows will
label this network "Unidentified" or "No internet access" — that is correct
and expected.** There is no internet on that cable; there is only the Pi.

Then, from the Pi side:

```bash
ssh pi@raspberrypi "cd wro2026 && ./tools/venue_net.sh status"
```

That reports three separate things, each stronger than the last:

- **cable** — a carrier exists. Proves a cable is plugged in, nothing more; a
  router or an idle port raises carrier too.
- **address server** — the Pi's dnsmasq is running.
- **lease** — a real machine asked the Pi for an address and got one. This is
  the only one that proves the laptop is genuinely there.

---

## Turning the radios off at the venue

Only once the wired link is proven:

```bash
./tools/venue_net.sh wifi-off
```

It **refuses** unless the laptop has actually taken an address and answers a
ping. That guard exists because a carrier alone is not evidence, and turning
Wi-Fi off with no real wired path locks you out of the robot completely.

`./tools/venue_net.sh wifi-on` undoes it. If you ever lose both, a screen and
keyboard on the Pi plus `nmcli radio wifi on` recovers it.

---

## Troubleshooting

| Symptom | Cause | Fix |
|---|---|---|
| No `192.168.50.x` address | adapter set to a static IP | set it back to automatic |
| No address, adapter shows `169.254.x.x` | no DHCP reply — Pi not booted, or cable in the wrong port | wait for the Pi to finish booting, check the cable |
| `raspberrypi.local` fails | Git Bash does not do mDNS - MEASURED here | use the hosts entry; do not rely on `.local` |
| bare `raspberrypi` fails on the cable | no DNS server on a direct link | add the hosts entry (`-AddHostsEntry`) |
| bare `raspberrypi` fails at home | hosts entry still set from the venue | remove it (`-RemoveHostsEntry`) |
| `ssh: connection refused` | Pi still booting | wait, then retry |
| Works, but you suspect it is going over Wi-Fi | both interfaces are up and mDNS picked the Wi-Fi one | test with `ssh pi@192.168.50.1` explicitly — that address only exists on the cable |
| Windows firewall prompt | new network classified Public | nothing to allow; SSH and VNC are outbound |

## Do not plug this port into a venue network

The Pi is a DHCP server on this cable. On a network that already has one, the
two fight. If you ever need the Pi on a normal network instead:

```bash
sudo nmcli con mod "Wired connection 1" ipv4.method auto
```

and set it back to `shared` afterwards.

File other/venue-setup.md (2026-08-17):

# Venue setup — wired networking, calibration, autostart

Everything needed on competition day, in the order you'll need it.

---

## 1. Wired networking — one cable, laptop to Pi

Laptop Ethernet port → Pi Ethernet port. Nothing else.

**Your laptop needs no setup.** Leave its wired adapter on *"Obtain an IP
address automatically"* — the default — and just plug in. The Pi runs the
address server itself, so it hands the laptop an address over the cable.

| | |
|---|---|
| Pi | `192.168.50.1` — fixed, always there |
| Laptop | `192.168.50.10`+ — given out by the Pi |
| Connect | `ssh pi@raspberrypi.local` |
| VNC | `raspberrypi.local:5900` |
| If `.local` fails | use `192.168.50.1` |

A **normal patch cable works** — Pi 4 Ethernet is auto-MDIX, so no crossover
cable is needed. Plug in, wait about five seconds, then:

```bash
ssh pi@raspberrypi.local
```

`raspberrypi.local` resolves over the cable because **avahi** (mDNS) runs on the
Pi and Windows 10/11 resolve `.local` natively.

### Wi-Fi and the cable together

They do not conflict, and you do not have to choose:

- **No cable** — Wi-Fi works exactly as normal. The Ethernet route exists but is
  marked `linkdown`, so it carries nothing.
- **Cable plugged in** — `192.168.50.x` goes over the cable, everything else
  still goes over Wi-Fi. The Pi's default route stays on Wi-Fi either way.

> **Testing at home, with both up:** the Pi advertises *both* of its addresses
> over mDNS, so `raspberrypi.local` may resolve to the **Wi-Fi** one and you
> will not actually be testing the cable. To prove the cable really works, use
> the address explicitly:
> ```bash
> ssh pi@192.168.50.1
> ```
> At the venue this cannot happen, because Wi-Fi will be off and
> `192.168.50.1` is the only address the Pi has.

### How it is set up

`eth0` uses NetworkManager's **shared** mode: a fixed `192.168.50.1/24` plus a
`dnsmasq` handing out `192.168.50.10–254`, started automatically at boot. Both
SSH and VNC already listen on every interface, so they need nothing enabling.

> This makes the Pi the address server on that cable. That is exactly right for
> a direct laptop link, but it means you should **not** plug this port into a
> venue network that has its own DHCP server — two servers on one network fight.
> If you ever need that instead:
> `sudo nmcli con mod "Wired connection 1" ipv4.method auto`

### Turning the radios off

Do this **only after** the cable is proven, and use the script:

```bash
./tools/venue_net.sh status      # says CONNECTED once the cable is in
./tools/venue_net.sh wifi-off
```

`wifi-off` refuses unless the cable is **physically connected**. It checks the
carrier, not the address — `eth0` keeps `192.168.50.1` even while unplugged, so
an address alone proves nothing. It also refuses if the address server is not
running, which would leave the laptop with no way in.

`./tools/venue_net.sh wifi-on` undoes it. If you ever lose both, a screen and
keyboard on the Pi plus `nmcli radio wifi on` recovers it.

## 2. Recalibrating for the venue's light

**Order matters.** Each step is measured through the previous one, so doing
them out of order silently invalidates the earlier work.

### Step 1 — camera, then colours

```bash
python tools/tune_colors.py
```

Guided and **headless** — it runs in a plain SSH terminal, no display needed.
It first re-locks exposure and white balance to the room, then walks through
blue, orange, green, red and magenta. You fill the middle of the view with each
object and press Enter; it samples the centre box, discards background by hue,
and builds a range from the percentiles.

Finally it checks **every pair for overlap**, because a range that is right on
its own is still wrong if it also matches the pillar beside it. That check is
what caught red swallowing magenta in testing.

```bash
python tools/tune_colors.py --check     # what do the current ranges see?
python tools/tune_colors.py red green   # redo just these two
```

`colors.json` and `camera_settings.json` are backed up to `.bak` first.

### Step 2 — the wall detector

```bash
python tools/tune_walls.py --detector
```

This is the one that is easy to miss. **The wall detector does not use a colour
range** — it uses `WALL_V_HARD` / `WALL_V_SOFT` / `WALL_S_MAX`, three
brightness/saturation cuts. Tuning the colours does *not* retune the walls.

It samples the wall, the mat, and a coloured line, then places the thresholds
in the gap between them. If the wall and mat overlap in brightness it says so
and writes nothing — that means the room is too dim and no threshold can work.

Results go to `wall_settings.json`, which `robot.py` loads automatically.

### Step 3 — distance calibration

```bash
python tools/tune_walls.py
```

The car never measures distance; it measures **density** — the fraction of one
half of the picture that is wall. This parks the car at several known distances,
fits a straight line, and prints the exact constants to paste into
`LANE_TARGET`, `OUTER_TARGET` and `WALL_EMERGENCY`.

Measure from the **side of the car** to the wall, at camera height, with the car
**parallel** to the wall. Parallel matters more than exact: at an angle the
camera sees a wedge of wall and reads high.

```bash
python tools/tune_walls.py --live    # live read-out while you move the car
```

**Re-run step 3 after step 2** — changing the detector changes every density.

### Step 4 — prove it

```bash
python tools/test_logic.py    # the brain, on synthetic numbers
python tools/dryrun.py        # both challenges, live camera, motor untouched
```

---

## 3. Running at the start line

### Which program runs

One line, at the top of `run.sh`:

```bash
PROGRAM="obstacle_challenge.py"
```

### Starting it automatically at power-on

```bash
./autostart.sh on
```

From then on: **power the car, wait for boot, press the button.** No laptop, no
terminal, no network. This is safe because the program waits for the button
before anything moves — booting into it just means the car is armed.

When a run finishes the program exits and the service restarts it, so it is
immediately re-armed for the next press. It never drives on its own.

| command | |
|---|---|
| `./autostart.sh on` | run at every boot |
| `./autostart.sh off` | stop doing that |
| `./autostart.sh status` | which program, is it armed, did it crash |
| `./autostart.sh log` | watch the live output |
| `./autostart.sh restart` | pick up an edited `run.sh` without rebooting |

After editing `PROGRAM`, run `./autostart.sh restart` (or just power-cycle).

### Running by hand instead

```bash
./run.sh                      # whatever PROGRAM says
./run.sh open_challenge.py    # override, just this once
```

---

## Quick reference

| | |
|---|---|
| Pi over cable | `ssh pi@raspberrypi.local` or `192.168.50.1` |
| Laptop wired adapter | leave on automatic DHCP — the Pi gives it an address |
| VNC | `raspberrypi.local:5900` |
| Radios off / on | `./tools/venue_net.sh wifi-off` / `wifi-on` |
| Recalibrate | `tune_colors.py` → `tune_walls.py --detector` → `tune_walls.py` |
| Verify | `tools/test_logic.py`, then `tools/dryrun.py` |
| Choose program | `PROGRAM=` at the top of `run.sh` |
| Arm at boot | `./autostart.sh on` |

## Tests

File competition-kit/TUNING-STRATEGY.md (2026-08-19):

# Tuning strategy — WRO 2026 Future Engineers

Team The Red Castle · HMK AI and Robotics Club

This is the field procedure. The PDF next to it has every tunable and the
control equations; this one is about **what to do, in what order, and how to
tell whether it worked**.

---

## The one idea behind all of it

The car has **no distance sensor**. Everything it knows comes from counting
pixels in one 320×120 image. So every number in both programs is really an
answer to *"how many pixels?"* — and a pixel count only means something on the
camera, the crop and the lighting it was measured on.

That is why the same class of bug has bitten this car five separate times:

| what happened | what it looked like |
|---|---|
| orange needed `V>125`, the line reads 78 | direction never locked CW |
| blue needed `V>70`, the line reads 43 | direction fell through to whatever fired |
| green needed `V>60`, the cube reads 38 | car ignored green pillars completely |
| line thresholds measured on a 2× crop, ours is 2.67× | both lines silently too high |
| neutral wall target 0.5, densities reach 0.25 | car drove straight out of the start into a wall |

**None of these looked like bugs.** A controller commanding zero looks exactly
like a controller that is happy. That is why the order below starts with
*looking at the image* and ends with *reading the log* — never with guessing.

---

## Order of work

Do these in order. Each step assumes the ones above are already right;
out of order, you are measuring through a mistake.

### 1 — Look at the image first

```bash
python tools/mask_debug.py
```

One picture, every mask the car uses: the camera view, the wall mask, blue,
orange, red, green, purple, each with its pixel count and percentage.

**Before any number, answer these by eye:**

- Are the walls solid in the WALL panel, or speckled and broken?
- Are the lines solid bands, or dotted and thin?
- Is the mat leaking into any coloured panel?

Venue lighting is the single biggest change between practice and competition.
If this picture looks wrong, nothing measured afterwards means anything.

### 2 — Walls, both directions

```bash
python tools/wall_calib.py cw       # park CENTRED, facing clockwise
python tools/wall_calib.py ccw      # flip it, same spot
```

**Centred is the whole point.** The target is the density a centred car reads,
so that a centred car is commanded to steer *zero*.

Two checks that catch a bad placement:

- The tool's own two halves should agree within about **0.01**. If left and
  right differ by 0.06, the car was not centred — the reading is of a car
  leaning on one wall, and putting it in the file bakes that lean into the run.
- CW and CCW should give **nearly the same number**, because both follow the
  outer wall. If they differ a lot, one placement was wrong.

A target wrong by 0.03 commands about 2° of steering while the car is already
centred — a constant lean, every cycle, all run.

### 3 — Lines

```bash
python tools/line_audit.py blue
python tools/line_audit.py orange
```

Park so the line fills the view. Set the threshold to roughly **77% of a full
line** — that is the ratio the original code used, and it leaves room for a
crossing seen at an angle.

Two things the tool tells you that a single reading cannot:

- **The frame-to-frame spread.** If the threshold sits *inside* it, the same
  crossing flickers on and off and gets counted twice.
- **Which bound is costing you pixels.** It reports, for each bound, how many
  pixels pass every *other* bound and fail only that one. A bound rejecting
  thousands is the one to move; a bound rejecting zero is doing nothing.

**Do not lower the blue saturation floor.** The mat's hue sits inside the blue
range — saturation is the only thing keeping it out.

### 4 — Pillars

```bash
python tools/sign_calib.py
```

Put a **green and a red cube side by side at equal distance** and run it.

The check that matters: **they should give equal area and equal `y`.** If one
is much smaller, that colour's range is clipping the cube, and no amount of
`kp` tuning will fix it — fix the colour first.

Green is the harder one, and always will be on this camera:

- the mat sits at **H70–79**; the green cube sits at **H≈71**. Same hue.
  Only saturation separates them.
- green is darker: **V≈38** against red's **≈72**.
- green demands the bigger manoeuvre — it must be passed on the left, so the
  aim runs far off frame.

### 5 — Parking walls (obstacle start only)

```bash
python tools/park_calib.py
```

Put the car in the start box exactly as it will start. The exit direction is
decided by `purple_left > purple_right`, so:

- **No purple at all** → that comparison is false → the car silently commits
  to CCW. The tool says so loudly.
- **Two sides nearly equal** → a few pixels of noise flips your lap direction.
  Move the car until one side clearly wins.

### 6 — Drive, then read the log

Every run writes its own timestamped file in `logs/`. Nothing is overwritten.

```bash
cd ~/wro2026 && source .venv/bin/activate && python open_challenge.py
```

**Tune from the log, not from memory of what the car looked like.** The log has
both wall densities, both pixel counts and their states, the target's x/y/area,
the traffic-light state, and the steering both before and after the clamp.

What to look for:

| symptom | look at | likely cause |
|---|---|---|
| leans into one wall all run | `dir_raw` on straights | target wrong — re-do step 2 |
| runs wide at corners | a run of `CLAMP` lines | `STEER_MAX` too low |
| stops early | `quadrant` jumps by 2 | phantom line — threshold too low, or orange catching red |
| ignores a pillar | `target_area`, `target_type` | min area too high, or the colour is clipping |
| swerves at nothing | `Err` large while area small | reacting to a distant sign |
| weaves on a straight | `dir_servo` reversals | gain too high, or smoothing too low |

---

## The surprise challenge

`tools/color_count.py` is written for this. Point the car at whatever the new
task involves and find its numbers:

```bash
python tools/color_count.py 90 135 --smin 140      # hue range, saturation floor
python tools/color_count.py 174 8  --smin 120      # a range that WRAPS (red)
python tools/color_count.py 40 80  --live          # keep printing while you move it
```

It prints the count, the left/right split, the biggest blob and its shape, and
the **H/S/V percentiles inside that blob** — which is what you set the
thresholds from. Set the floors just outside p05/p95, never at p50.

Then in the program you write on the day:

```python
from color_count import grab, color_count, halves, biggest_blob

frame, hsv = grab(cam)
n, mask = color_count(hsv, hue=(90, 135), s_min=140, v=(20, 200))
if n > 800:
    left, right = halves(mask)
```

It works on the same 320×120 frame as both challenge programs, so a threshold
measured with the tool drops straight in without rescaling.

---

## Rules of thumb, in priority order

1. **Slow the car down before tuning anything.** Every threshold is easier to
   hit at low speed, and `speed` is one line.
2. **If something is not detected, check the V floor first.** Three separate
   colours on this car were rejected by a brightness floor set on a brighter
   camera.
3. **Never change a threshold and the crop in the same session.** `CROP_TOP`
   invalidates *both* the wall targets and the line thresholds.
4. **Change one number, do one run, read the log.** Two changes at once and you
   learn nothing from the result.
5. **Saturation separates colour from mat; brightness separates object from
   shadow.** When a mask leaks, ask which of those two jobs is failing.
6. **Write down what you changed.** Both programs print every tunable at
   startup, so the run's own log says what produced it — keep the logs.

---

## If everything goes wrong at the venue

- `git log --oneline` on the laptop — every version is committed, and the
  commit messages say what was measured and why.
- `backups/` holds snapshots pulled from the Pi.
- Both programs fall back safely: if `pigpiod` is not running the servo still
  works (it just buzzes), and both say so loudly at startup rather than
  failing silently.
- The startup banner prints every tunable. If the car behaves unexpectedly,
  **read the banner first** — it is faster than reading the file.

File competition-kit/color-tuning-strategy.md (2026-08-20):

# Colour tuning strategy

Everything here was **measured on this car**, on this field, with these two
programs. Numbers without a measurement behind them are marked as such.

---

## The single most important fact

> **Every colour failure on this car has been a BRIGHTNESS FLOOR, not a hue.**

Five separate times. Each one was a `V >` floor inherited from a camera brighter
than ours, and each one silently discarded most or all of the object:

| object | their floor | its real V on our camera | what happened |
|---|---|---|---|
| blue line | `V > 70` | p50 **43**, p95 79 | most of the line rejected |
| orange line | `V > 125` | p50 **78**, p95 106 | orange could **never** fire |
| green cube | `V > 60` | p50 **38**, p99 61 | kept **16 of 1107 px — 1%** |
| purple parking wall | `v >= 70` | p50 **67**, p05 52 | over half the wall discarded |
| wall detector | `v < 70` alone | — | counted shadow as wall |

Our whole frame tops out around **V = 137–143**. Any inherited threshold above
about 60 is suspect on this camera. **When a colour is not detected, check its
brightness floor first.**

---

## What every colour actually measures here

Measured with `tools/line_audit.py`, `tools/sign_calib.py`, `tools/park_calib.py`.

| object | hue | saturation | value | separated from the mat by |
|---|---|---|---|---|
| **mat** (the adversary) | **70–79** | p50 93, p99 146 | p50 135 | — |
| blue line | 90–135 | p50 228 | p50 43 | saturation |
| orange line | 0–30 | p50 167 | p50 79 | hue |
| red cube | 0–7 | p50 216 | p50 72 | hue |
| green cube | **p50 71** | p50 247, p01 157 | p50 38 | **saturation only** |
| purple wall | 163–179 | p50 198 | p50 67 | hue |
| black wall | — | low | < 32, or < 62 desaturated | brightness |

### The two facts that explain most of the difficulty

**1. The mat sits in the green hue band.** Mat H70–79, green cube H p50 **71**.
They are the *same hue*. Hue cannot separate green from the floor — only
saturation can, and the gap is narrow: mat p99 **146** against cube p01 **157**.
That is why `GREEN_SAT_MIN = 150` and why lowering it re-admits the mat. If you
ever drop green's V floor further, you **must** keep S high.

**2. Orange and red share a hue band.** Red measures H0–7; the orange line band
is H0–30. A red pillar can pad the orange count. This is why orange is the
unreliable line and blue is the trustworthy one.

---

## The order to tune in, and why

### 0. Lock the exposure before anything else

Auto-exposure and auto-white-balance move **every threshold below** while the
car drives. They are already locked:

```
AeEnable False, ExposureTime 12000, AnalogueGain 8.0
AwbEnable False, ColourGains (1.329, 1.446)
```

If you change exposure at the venue, **every colour must be re-measured.** Treat
that as a last resort, not a first move.

### 1. Hue — widest bound, least often wrong

Hue is the most stable property under changing light. Set it generously and
leave it. In five failures, hue was the culprit **zero** times.

Only two hue edges here are delicate, and both are collisions rather than
lighting:

- **red's wrap vs the purple wall.** Red matches `h < 15 or h > RED_HUE_HI`. The
  parking wall reaches **H179**. With `RED_HUE_HI = 175`, red claims **4558 px
  of the wall** — measured. Raising it to 178+ is the fix if red ever "sees a
  sign" that is really the parking wall.
- **green's floor vs nothing.** Green's band is wide and safe; its problem is
  never hue.

### 2. Saturation — this is what excludes the mat

Saturation is the bound doing the real work of keeping the floor out.

- **blue**: `S > 140`. Measured, **9556 px** pass every other bound and fail only
  this one — that is the mat, whose hue drifts into blue's range. Lowering this
  re-creates a bug we already fixed once.
- **green**: `S > 150`. At 120 the mat leaks 61 px; at 150 it leaks **zero**
  while keeping 1088 of 1107 cube pixels.
- **orange**: `S > 70` is loose, and it can afford to be — hue already separates
  orange from the mat (H13 vs H70).

### 3. Brightness — last, and LOW

This is the one that has broken every time. Set it just low enough to keep the
object, no lower.

The method: isolate the object by hue+saturation alone, then look at how many of
**its own pixels** each candidate floor would keep. For the green cube:

```
V > 10  keeps 1097 of 1107  (99%)
V > 25  keeps 1088          (98%)     <- chosen
V > 30  keeps 1033          (93%)
V > 40  keeps  334          (30%)
V > 60  keeps   16          ( 1%)     <- was here
```

The cliff between 30 and 40 is the cube's actual brightness distribution. Sit
clearly below the cliff.

---

## The diagnostic that replaces guessing

Do not tune by changing a number and re-running. For each bound, count the
pixels that pass **every other bound** and fail **only that one** — the marginal
cost of that bound. `tools/line_audit.py` prints exactly this:

```
pixels that pass every OTHER bound and fail only this one:
    hue >  90      rejects    580 px
    hue <  135     rejects      0 px      <- doing nothing, could be removed
    sat >  140     rejects   9556 px      <- this is the MAT, leave it alone
    val >  20      rejects     76 px
    val <  200     rejects      0 px      <- doing nothing
```

Read it as: a bound rejecting thousands is either doing essential work (the mat)
or destroying your object — look at *what* it is rejecting before deciding. A
bound rejecting zero is doing nothing at all.

---

## Two rules that prevent the classic mistakes

### Never tune from a single number

A count of 1200 px means nothing on its own. Measure the **object** and the
**background** in the same frame. Blue reads 1036 on the line and **3–9 on bare
mat** — that ratio is what makes the threshold safe, not the 1036.

### Thresholds belong to a CROP, not just a camera

`CROP_TOP` changes every pixel count. Ours is 160 where theirs was 240, which
squashes 320 rows into 120 instead of 240 into 120 — so the same physical line
lands on **76%** as many pixels (measured; geometry predicts 75%).

That is why their 1100/1300 became **830/930** here. **If you ever change
`CROP_TOP`, every pixel-count threshold must be re-measured.** Areas too: a
pillar keeps about 75% of its area, which is why the sign area gates were
rescaled.

---

## At the venue

Venue light changes **V** most, **S** second, **H** least. So:

1. Run `tools/line_audit.py`, `tools/sign_calib.py` and `tools/park_calib.py`
   on the actual field first.
2. If something is missed, check its **V floor** before touching anything else.
3. Re-check the **mat's** S — if the venue floor is shinier, the mat's
   saturation rises and green's 150 gap narrows.
4. Only re-measure hue if a colour is being *confused* with another, not merely
   missed.

**Do not change exposure at the venue** unless nothing else works. It invalidates
every number in this document.

---

## Setting NEW HSV at the venue — the actual procedure

The other tools *check* bounds you already have. `hsv_pick.py` *proposes* new
ones from whatever the object measures under the venue's light.

**For each colour that needs redoing:**

```bash
python tools/hsv_pick.py green
python tools/hsv_pick.py orange
python tools/hsv_pick.py red --wrap      # red's hue wraps past 0
```

Park so the object **fills as much of the view as you can**, with nothing else
coloured in frame. The tool finds the most saturated large blob, measures its
H/S/V over several frames, and prints lines you can paste straight in.

It then re-counts with those bounds and reports two numbers:

```
of the object     : 1088 of 1107 px kept   (98%)
of everything else: 0 px let in
```

**The second number is the one that matters.** Bounds that catch the object are
easy; bounds that catch the object *and not the mat* are the job.

**Then check the other direction** — this is the step people skip:

```bash
# move the object OUT of view, then:
python tools/color_count.py <the six numbers it gave you>
```

A threshold is only safe when you know **both** readings. Blue reads 1036 on the
line and 3–9 on bare mat; that *ratio* is what makes 830 safe, not the 1036.

### The order to do them in at the venue

1. **Nothing at first.** Run `wall_calib.py cw` — if the wall densities are
   close to 0.215 a side, the light has not moved much and you may need nothing.
2. **Whichever colour is missed**, in this order of likelihood: green (darkest),
   orange, blue, purple. Red has never needed it.
3. **Re-check the mat** with `color_count.py 45 90 0 255 0 255` — if the venue
   floor is shinier its saturation rises, and green's 150 gap narrows.
4. **Re-measure the line thresholds** with `line_audit.py` after any blue or
   orange change — the HSV bounds and the pixel thresholds are not independent.

### What NOT to do

Do not change exposure. Every number in this document is measured at
`ExposureTime 12000, AnalogueGain 8.0` with AWB locked. Changing it invalidates
all of them at once, and you will not have time to redo everything.

---

## Adding a new colour (surprise challenge)

Use `tools/color_count.py`. It gives a pixel count for any HSV range through the
same pipeline the car uses, so a number you measure with it means the same thing
as a number in the programs:

```python
from color_count import color_count
n = color_count(hsv, h=(35, 85), s=(120, 255), v=(40, 255))
```

Tune it in the order above — hue wide, saturation to exclude the mat, brightness
last and low — and always measure the background in the same frame.

---
---

# Every colour, one at a time

Six masks matter on this car. For each: what it decides, where its numbers live,
what it actually measures here, what breaks it, and how to check it.

---

## 1. BLUE — the counted line

**Decides:** the quadrant count, and in the open challenge the lap direction.
This is the line to trust.

| | |
|---|---|
| constants | `BLUE_HUE_MIN/MAX = 90, 135`, `BLUE_SAT_MIN = 140`, `BLUE_VAL_MIN/MAX = 20, 200` |
| threshold | `blue_line_threshould = 830` |
| measured on the line | H 90–107, S p50 **228**, V p50 **43** |
| measured on bare mat | **3–9 px** |
| on the line, static | 1017–1048 px |
| driving over it | peaks **1883–3624** |

**What breaks it:** the brightness floor. Their `V > 70` against a real V of 43
cut most of the line away.

**What must not move:** `BLUE_SAT_MIN = 140`. Measured, **9556 px** pass every
other bound and fail only this one — that is the **mat**, whose hue drifts into
blue's range. Saturation is the only thing keeping the floor out of the blue
count. Lowering it re-creates a bug already fixed once.

**The hue floor costs 580 real line pixels** (the blurred edges, where averaging
pulls the hue down) and could be lowered to about 88 — but green pillars measure
H81–86 and the obstacle program shares this range, so it stays at 90.

**Check it:**

```bash
python tools/line_audit.py blue
```

It fires with about 1.2x margin on the worst frame, and the tool warns if the
threshold sits inside the frame-to-frame spread — which is what made it flicker
before.

---

## 2. ORANGE — the other line

**Decides:** the lap direction in the open challenge, and the corner kick in the
obstacle one. **Less reliable than blue, structurally.**

| | |
|---|---|
| constants | `ORANGE_HUE_MIN/MAX = 0, 30`, `ORANGE_SAT_MIN = 70`, `ORANGE_VAL_MIN/MAX = 30, 240` |
| threshold | `orange_line_threshould = 930` |
| measured on the line | H 5–26, S p50 **167**, V p50 **79** |
| measured on bare mat | 0–87 px |
| on the line, static | 1107–1196 px |

**What breaks it:** brightness again. Their `V > 125` against a real V of 78
meant orange could **never** fire — the direction fell through to blue every
time, and a clockwise run then followed the inner wall.

**Its structural problem: red lives in its hue band.** Red measures H0–7; the
orange band is H0–30. A red pillar pads the orange count. Measured in a CCW run,
orange reached **845** against its 930 threshold from pillars alone — 9%
headroom. This is why the obstacle program can be set to count blue only.

**Its saturation floor is loose (70) and can afford to be** — hue already
separates orange from the mat (H13 vs H70). Do not tighten it to fix red; that
is a hue collision, not a saturation one.

**Check it:**

```bash
python tools/line_audit.py orange
```

---

## 3. RED — the pillar you pass on the RIGHT

**Decides:** steer right, and `last_detected_traffic_light`.

| | |
|---|---|
| constants | `RED_HUE_LO/HI = 15, 175` — matches `h < 15` **or** `h > 175` |
| | `RED_SAT_MIN = 120`, `RED_VAL_MIN/MAX = 60, 240` |
| measured on the cube | H **0–7**, S p50 **216**, V p50 **72** |
| area at calibration distance | **1218 px**, box 36 × 44 |

**Red works.** It is the one colour that has never needed a brightness fix — its
V of 72 clears the 60 floor.

**Its one real hazard: the magenta parking wall.** The wall measures up to
**H179**, and red matches everything above `RED_HUE_HI = 175`. Measured with the
car in the start box, **red claims 4558 px of the parking wall** — wall being
reported as a sign.

Since red's own hue is only H0–7, the upper arm of that wrap does nothing for red
and everything for the false positive. **Raise `RED_HUE_HI` to 178–179** if red
ever "sees a sign" that is really the parking wall.

**Check it:** park facing a red cube and run

```bash
python tools/sign_calib.py
```

---

## 4. GREEN — the pillar you pass on the LEFT

**Decides:** steer left. The hardest colour on this field, for two reasons.

| | |
|---|---|
| constants | `GREEN_HUE_MIN/MAX = 45, 90`, `GREEN_SAT_MIN = 150`, `GREEN_VAL_MIN/MAX = 25, 240` |
| measured on the cube | H **p50 71**, S p50 **247** (p01 157), V p50 **38** (p99 61) |
| area at calibration distance | **1279 px**, box 38 × 46 |

**Reason one — it is dark.** V p50 38 against their `V > 60` floor kept
**16 pixels of 1107**. One percent. Green never reached the minimum area, so no
green target was ever built and the sign law never saw one. Every "it does not
avoid the green pillar" report traced back to here.

```
V > 10  keeps 99%       V > 30  keeps 93%
V > 25  keeps 98%  <--  V > 40  keeps 30%
                        V > 60  keeps  1%   <-- was here
```

**Reason two — the mat is the same hue.** Mat H70–79, cube H p50 **71**. Hue
cannot separate them at all. Only saturation can, and the gap is narrow:

| S floor | cube kept | mat leaked |
|---|---|---|
| 100 | 1088 | 335 |
| 120 | 1088 | 61 |
| **150** | **1088** | **0** |

So **if you ever lower green's V floor further, you must keep S at 150 or
above.** Dropping both at once puts the floor into the green mask, and the car
steers for a patch of mat.

**Check it:** put a green and a red cube at equal distance and run

```bash
python tools/sign_calib.py
```

The check that matters is not the absolute number — it is that green and red
report the **same area and the same y** at equal distance. Before the fix they
were 10 vs 1222; after, 1279 vs 1218, a ratio of 1.05.

---

## 5. MAGENTA / PURPLE — the parking walls

**Decides:** which way to leave the parking lot, and therefore the whole lap
direction. Also an obstacle to avoid during the laps.

| | |
|---|---|
| constants | `PURPLE_HUE_MIN/MAX = 135, 175`, `PURPLE_SAT_MIN = 120`, `PURPLE_VAL_MIN/MAX = 60, 240` |
| measured on the wall | H **163–179** (p50 174), S p50 **198**, V p50 **67** (p05 52) |
| in the start box | left 5065 px, right 5952 px |

**Two bounds are cutting the wall:**

1. **`V > 60` against a wall at V p50 67, p05 52.** Measured, that keeps only
   **77%** of it; `V > 30` keeps 99%.
2. **`H <= 175` against a wall reaching H179.** Measured, that bound alone
   rejects **4558 px** — and those are the very pixels red then claims.

**How the direction is decided, and how it fails:**

```python
if purple_left > purple_right:  direction = CW     # way out is RIGHT
else:                           direction = CCW    # way out is LEFT
```

With **no purple in view at all** the comparison is `False`, so the car silently
commits to CCW. It looks like a decision and is really a fall-through. The
program now warns loudly when the total is under 200 px.

The second failure mode is the two sides being **too close**: measured 5065 vs
5952 is a ratio of only **1.17**, and a little noise flips the lap direction.
Park so one side clearly wins.

**Check it:** put the car in the start box exactly as it will start, and run

```bash
python tools/park_calib.py
```

---

## 6. BLACK — the walls

Not a colour mask. The wall detector uses brightness and saturation together
plus a **geometric** test, and none of it goes through `colors.json`.

| | |
|---|---|
| constants | `WALL_V_HARD = 32`, `WALL_V_SOFT = 62`, `WALL_S_MAX = 90` |
| | `WALL_OPEN_K = 3`, `WALL_MIN_RUN = 6` |
| centred density | **0.215** per side |

```
wall = (V < 32)  or  (V < 62 and S < 90)
```

**Why two cases and not one threshold:** HSV saturation is unreliable when V is
tiny — a black wall can report S>200 from pure sensor noise. Testing saturation
alone therefore **rejects real walls**, and testing brightness alone **accepts
the coloured lines**. Hence: very dark is wall whatever S says; dark *and*
desaturated is wall; dark but saturated is a line, not wall.

**The shadow test is geometric, not colour.** A real wall is a **tall solid
vertical run**; a shadow is a broad shallow smear. Any dark region without a run
of `WALL_MIN_RUN = 6` rows is discarded. On the field this removed the mat's
printed dots — 327 px, sitting on the left, which had been inflating
`left_wall` specifically.

- Shadow still getting through → **raise** `WALL_MIN_RUN`
- Distant walls dropping out of the reading → **lower** it

**Check it:**

```bash
python tools/wall_calib.py cw      # then flip the car, and ccw
```

The check that matters: a **centred** car must read left and right within about
0.01 of each other. When CW read 0.2415 / 0.1825 — a gap of 0.059 — that was not
a camera asymmetry, it was the car not actually being centred, and it produced a
target telling the car to hold 13% closer to one wall for the whole run.

---

# The collision map

Two pairs share hue space. Neither can be fixed with saturation or brightness —
only by moving a hue edge, or by not relying on the weaker one.

```
  H0        H7   H15                H30
  |---------|     |------------------|
  RED cube        ORANGE line band            red pads the orange count

                       H70  H79   H90
                       |-----|
                       MAT          green band starts at H45
                       green cube sits at H71, INSIDE the mat

       H163                      H175  H179
       |--------------------------|-----|
       PURPLE wall                      red's wrap starts at 175,
                                        so red claims H176-179 of the wall
```

| collision | why saturation cannot fix it | what to do |
|---|---|---|
| red vs orange line | red is genuinely inside the orange hue band | count **blue** instead — it has no twin on this field |
| green vs mat | identical hue, H71 both | saturation is the *only* separator; keep `GREEN_SAT_MIN` at 150 |
| red vs purple wall | red's wrap overlaps the wall's top hue | raise `RED_HUE_HI` past H179 |

---

# One-page tuning order

1. **Lock the exposure.** Changing it invalidates every number in this document.
2. **Hue** — set wide, and touch it only to fix a *collision*, never a *miss*.
3. **Saturation** — the bound that excludes the mat. Blue 140, green 150.
4. **Brightness — last, and low.** Five failures out of five were here.
5. **Measure the object AND the background in the same frame.** A count without
   its background is not a threshold.
6. **Re-measure everything if `CROP_TOP` changes.** Pixel counts and areas both
   scale with the crop — ours keeps 76% of what theirs did.

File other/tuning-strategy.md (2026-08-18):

# Tuning strategy — what to do at the venue, in order

The venue's light is different, and **almost every number in this car is a
measurement taken through that light.** This is the order to redo them in.
Each step is measured *through* the ones before it, so doing them out of order
silently invalidates the earlier work.

Budget about **40 minutes** for a full pass.

---

## The one rule

> **Change one number. Run. Read the log. Repeat.**

Changing two things and running once tells you nothing about either. Every run
writes a CSV to `logs/`, and that log is the only honest account of what
happened — not what you saw from the side of the track.

---

## Step 0 — before you touch anything (2 min)

```bash
cd ~/wro2026 && source .venv/bin/activate
python tools/test_logic.py     # must say ALL TESTS PASSED
./tools/venue_net.sh status    # can you still reach the Pi?
```

If the tests fail, fix that first. Everything below assumes the logic is sound
and only the *numbers* are wrong.

---

## Step 1 — camera, then colours (15 min)

```bash
python tools/tune_colors.py
```

Headless, so a plain SSH terminal is enough. It re-locks exposure and white
balance to the room **first**, then walks each colour.

**Why the order cannot be swapped:** every colour is measured *through* the
white balance. Re-locking it afterwards throws away every colour you just
tuned.

Then prove it:

```bash
python tools/tune_colors.py --check
```

**What you are looking for:** zero overlap between every pair. A range that is
right on its own is still wrong if it also matches the pillar beside it. This
check is what caught red swallowing the magenta parking wall.

---

## Step 2 — what counts as a wall (5 min)

```bash
python tools/tune_walls.py --detector
```

**This is the step everyone forgets.** The wall detector does **not** use a
colour range — it uses three brightness/saturation cuts. Tuning the colours
does *not* retune the walls. If it says wall and mat overlap in brightness, the
room is too dim and no threshold can work; add light.

---

## Step 3 — centimetres to density (10 min)

```bash
python tools/tune_walls.py
```

The car never measures distance. It measures **density** — how much of the
picture a wall fills. This parks it at known distances, fits a line, and prints
the constants to paste in.

Measure from the **side of the car**, at camera height, **parallel** to the
wall. Parallel matters more than exact: at an angle the camera sees a wedge and
reads high.

**Re-run this after Step 2** — changing the detector changes every density.

---

## Step 4 — the corner lines (5 min)

```bash
python tools/line_check.py
```

Point the car at a real corner line, then at bare mat.

**What you are looking for:** on the line, ONE wide shallow blob. On bare mat,
nothing. Scattered blobs or a tall blob mean the colour is matching something
else — and no threshold fixes that, so go back to `tune_colors.py`.

This matters more than it looks. **The first line the car crosses decides which
way round the track it drives**, and a wrong direction ruins the entire run.

Measured on this car: blue was triggering on **39–54 % of frames** — it was
matching the mat's near-field colour cast, not the line. Raising blue's bar from
0.035 to 0.100 put it in the gap between the noise (peaks ≤ 0.084) and real
crossings (peaks ≥ 0.114).

---

## Step 5 — the parking lot, if you use it (3 min)

```bash
python tools/park_check.py
```

Put the car where it will actually start.

**What you are looking for:** a margin of **1.5× or better**. Below that it is
close to a coin toss — turn the car so one magenta wall clearly fills more of
one half. If it picks the wrong way out, flip `PARK_INVERT`.

---

## Step 6 — prove it without driving (2 min)

```bash
python tools/dryrun.py
```

Both challenges against the live camera, motor never touched. Nothing here
should surprise you before you let the car move.

---

# Tuning the driving itself

Only after the perception above is right. **A control problem you can see is
usually a perception problem you cannot.**

## If it hits walls

| symptom in the log | change |
|---|---|
| many frames past `WALL_EMERGENCY` | lower `SIGN_WALL_GUARD` (0.7 → 0.5) so signs stop pulling it in |
| it hugs the outer wall | raise `LANE_DISTANCE_CM` |
| it wanders in the middle | raise `OUTER_KP` |
| it weaves / oscillates | lower `OUTER_KP`, or raise `OUTER_DEADBAND` |

## If it mishandles signs

| symptom | change |
|---|---|
| chases distant specks | raise `GREEN_MIN_AREA` / `RED_MIN_AREA` |
| notices signs too late | lower them |
| calls a line or floor patch a sign | raise `*_MIN_ASPECT` toward 1.5 |
| passes too close | move `*_TARGET_X` further from 160 |
| swings too hard | lower `*_KP` |
| abandons a pass halfway | raise `SIGN_HOLD_S` |
| drives straight too long after one | lower `SIGN_STEER_HOLD_S` |

**Green and red are tuned separately** and genuinely need it: on one run green
was detected at a median area of **186 px** and red at **718**.

## If corners go wrong

| symptom | change |
|---|---|
| turns the wrong way at every corner | the DIRECTION is wrong — Step 4 |
| cuts corners | raise `KICK_ANGLE` or `KICK_TIME_S` |
| swings too wide | lower them |
| stops in the wrong place | `STOP_EXTRA_S` |

---

## Reading a log fast

```bash
ls -t logs/*.csv | head -1        # the newest run
```

Three columns tell you most of it:

- **`dir`** — does it change, or lock at `t=0.000`? Locking instantly means it
  decided from a line merely *in view* at the start.
- **`mode`** — if `wall` is more than ~15 % of frames, the car is fighting the
  track, not driving it.
- **`quad`** — should reach 12 and no more. Higher means the line logic is
  counting things that are not corners.

---

## What NOT to do at the venue

- **Do not** change the control gains before the colours are right.
- **Do not** change two numbers between runs.
- **Do not** tune from what you saw. Tune from the log.
- **Do not** turn Wi-Fi off until `venue_net.sh status` says the laptop is
  ANSWERING. Carrier alone is not proof, and getting this wrong locks you out
  of the robot entirely.

---

# Backups — before you change anything

```bash
./backup.sh save "worked at the venue"    # snapshot the Pi as it is NOW
./backup.sh list                          # what you have
./backup.sh restore <name>                # put one back on the Pi
./backup.sh undo                          # undo the last push or restore
```

A snapshot is the five code files **plus every calibration file** — the numbers
that took hours to measure and cannot be re-derived from anything else. Each one
is stored in three places: here on the laptop, as a git tag, and on GitHub.

**`./sync.sh push` snapshots the Pi automatically before overwriting it**, so a
bad push is always one `./backup.sh undo` away.

**Take a snapshot the moment a run goes well.** That is the whole point — you
cannot get back to a configuration you never recorded, and "it was working an
hour ago" is not a state you can restore.

After any restore, prove it before driving:

```bash
ssh pi@raspberrypi 'cd wro2026 && source .venv/bin/activate && python tools/test_logic.py'
```

## The one backup this does not cover

If the **SD card itself** dies or corrupts, none of the above helps — the
operating system, the Python environment and the camera drivers are all on it.
Image the card from another machine while things are working:

- **Raspberry Pi Imager** → *Utilities* → read the card to a `.img` file, or
- Windows: **Win32DiskImager** → *Read*

Do this once, now, and keep the image somewhere other than this laptop. It is
the difference between a twenty-minute swap and losing the competition.

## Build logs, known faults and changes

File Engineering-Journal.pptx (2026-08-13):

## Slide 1


Engineering Journal

WRO 2026 Future Engineers — Self-Driving Cars

Team The Red Castle | HMK AI and Robotics Club

Coach: Ahmad Kalthom | Jolian Wassof · Omar Shammout · Louay Rashwan

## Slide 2

Table of Contents

• 1. Introduction
• 2. Solution
- 2.1 Open Challenge
- 2.2 Obstacle Challenge
• 3. Mobility Management
- 3.1 The Steering Assembly
- 3.2 The Driving Assembly
- 3.3 The Robot's Body / 3D Design
- 3.4 Mobility Measurement
• 4. Power and Sense Management
- 4.1 The Robot's Power Source
- 4.2 Main Components
- 4.3 Wiring Diagram
- 4.4 Sensing
• 5. The Robot's Evolution
- 5.1 Past 5.2 Present 5.3 Future
• 6. The Vehicle's Photos
• 7. Team
• 8. Links and Credits

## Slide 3

1. Introduction

Self-driving cars are one of the clearest places where robotics, computer vision and control theory meet in a single physical object that either works or doesn't. For WRO 2026 Future Engineers, our goal was to build a vehicle that finds its own way around a track it has never measured, using only what a camera can see.
We built our car around a Raspberry Pi 4 and a single wide-angle camera. No LiDAR, no ultrasonic rangefinders, no wheel encoders, no IMU. Everything the rules require the car to know — where the walls are, which way to lap, where the traffic signs are, where to park — is visible to a camera, so we put our engineering time into making that one sensor trustworthy instead of into fusing several imperfect ones.
That decision shaped most of what follows. A camera-only car lives or dies on image quality and threshold tuning, and a large part of this document is the story of getting those right: a sensor swap that fixed a depth-of-field problem we didn't expect, a wall detector that turned out to be reading corner lines as walls, and a control law that we rebuilt once we had a correct measurement to calibrate it against.
The vehicle drives the Open Challenge — three laps around a track whose inner wall positions are randomised each round — and the Obstacle Challenge, which adds red and green traffic signs that must be passed on the correct side and a parking manoeuvre at the end.

1

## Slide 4

2. Solution

2.1 Open Challenge

The Open Challenge is three laps of a track whose inner wall positions are randomised each round, so nothing about the corridor width can be hard-coded in advance — the car has to read it from the camera as it drives.

• Direction is decided once, from the first corner line the camera sees, and locked for the rest of the run — whichever colour reads bigger in that frame sets clockwise or counter-clockwise, and the reading is cross-checked against which side of the image has more open wall as a second opinion.
• Between corners, a proportional-derivative controller holds a fixed distance to the outer wall only. We deliberately do not centre between both walls: the inner wall moves every round, so the outer wall is the one reference that stays put.
• At a corner, crossing the driving-direction's line fires a scripted turn — full steering lock held for a bounded time, ending as soon as the way ahead reads clear rather than after a fixed duration.
• A wall emergency always wins, in any state: if either wall gets too close the car escapes proportionally to how close it is, and if both walls are close at once (jammed facing a corner) it commits to a single escape direction instead of wavering between two.
• The car stops once 11 quadrants are counted and the lap timer has run out, so it finishes driving through the last straight instead of halting on the line itself.

2

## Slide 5

2. Solution

2.2 Obstacle Challenge

The Obstacle Challenge adds red and green traffic signs that must be passed on the correct side, then a parking manoeuvre once the laps are done.

• If a sign is visible, the car steers to place it correctly — red on the car's right, green on its left — with the target position sliding further toward the frame edge as the sign gets closer, so the manoeuvre curves rather than swerving late.
• If a sign was visible a moment ago but drops out of view for a frame, the last steering command is held rather than reacted to — sign detection can flicker sharply between consecutive frames, and reacting to every drop-out broke passes mid-way.
• Between signs, the car falls back to the same outer-wall lane-keeping law used in the Open Challenge, instead of driving straight and hoping a wall override corrects it in time.
• A wall override sits above all of this and also does the job of turning the car through each corner, since there is no separate scripted-turn sequencer here.
• Parking is not yet wired into the main loop — the magenta gate is currently treated purely as a wall to avoid. This is called out honestly in the Evolution section.

3

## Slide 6

3. Mobility Management

3.1 The Steering Assembly

Steering is Ackermann-style, driven by a single SG90 micro servo (GPIO13, which is a hardware-PWM pin — a smoother, lower-jitter signal than a software-timed one).
The servo turns a central bell-crank, which pushes a tie-rod out to both front steering knuckles. Because the linkage geometry is Ackermann and not a simple parallel arm, the inner wheel turns through a sharper angle than the outer one in a corner — each wheel follows its own turning radius instead of fighting the other and scrubbing.
The linkage's mechanical limit is ±35°. In software we run it at ±20° (STEER_MAX in config.py) for stability at full driving speed — the wider mechanical range is there if a future tuning pass wants it.
Every steering command in the codebase passes through this one constant and one servo() function, so there is exactly one place that ever needs to know the true centre position — the field-calibrated trim is stored in servo_center.txt (currently -9°) and applied automatically.


Front steering linkage, top view


Steering turned, showing the linkage sweep

4

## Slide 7

3. Mobility Management

3.2 The Driving Assembly

Drive comes from an N20 geared DC motor rated 12 V, 200 rpm, chosen for its compact size and enough torque to pull the car away from rest repeatedly without stalling.
The motor is controlled by an L9110S dual H-bridge, wired so one input is held low while the other carries the PWM speed signal (GPIO24 = forward, GPIO23 = reverse). In software, motor() never switches directly from forward to reverse — it coasts to a stop and waits first, because slamming the direction while the motor is still spinning drives its back-EMF onto the supply rail and can destroy the Pi's regulator. We found this out by losing a regulator early in the build.
From the motor, a 25-tooth pinion drives a 20-tooth gear (a 1.25:1 reduction) into a 3D-printed differential we designed ourselves — outer shell, outer ring gear, and two inner bevel gears on long and short shafts. The differential is the single change that let us raise the steering limit: with a solid axle, the outer wheel scrubbing against the inner one through a corner cost so much traction we had to cap steering near 8° just to keep the car from stalling mid-turn.


N20 motor driving the differential gear mesh


Rear axle, front view

5

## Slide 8

3. Mobility Management

3.3 The Robot's Body / 3D Design

The chassis was designed in Fusion 360 and printed in PLA+ Silk Silver on a Bambu Lab A1: a base plate, a middle plate and a top plate carrying the Pi, battery, driver, buck converter and the camera mast, sized to keep mass low and central over the wheelbase.


Full car assembly

Mass 407 g, overall footprint 14.2 x 9.3 x 15 cm, wheelbase 9.4 cm, rear track 8.5 cm — a wheelbase-to-track ratio close to 1:1, a stable proportion for cornering without tipping risk at this size.

6

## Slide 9

3. Mobility Management

3.4 Mobility Measurement

To reason about how fast the car can safely go, we worked through the drivetrain's speed chain from the motor to the ground:

Wheel radius (rw):
rw = 4.7 cm / 2 = 2.35 cm = 0.0235 m
Wheel perimeter (Pw):
Pw = 2π·rw = 2 × 3.1416 × 0.0235 ≈ 0.1477 m
Motor speed and the gear reduction:
ωmotor = 200 rpm (rated, no load)
ωaxle = ωmotor / 1.25 (25:20 reduction) = 160 rpm
Ground speed (theoretical, no load):
v = Pw · ωaxle = 0.1477 × 160 ≈ 23.6 m·min⁻¹
v ≈ 0.394 m·s⁻¹ (≈ 39 cm/s)
This is a ceiling, not a running speed: tyre friction, the differential, and the car's own 407 g mass all take a share of it. What actually governs how fast the car drives in competition is the 100% cruise setting in software, which cruise_speed() then eases back automatically whenever the steering is working hard — fast on the straights, deliberately slower through a turn.

7

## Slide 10

4. Power and Sense Management

4.1 The Robot's Power Source

Power comes from three 18650 Li-ion cells in series — about 11.1 V nominal, up to 12.6 V fully charged — feeding two separate rails rather than one shared one:
The motor is wired straight from the battery to the L9110S driver's supply pin, with nothing in between. A separate DC-DC step-down converter, rated at 5 V and at least 3 A, powers the Raspberry Pi and the servo on its own rail.
This split exists because of a real failure: early on, the motor and the Pi shared one supply, and the Pi rebooted every time the motor drew current under load — a classic brownout, made worse by the driver's ground not being tied back to the Pi's ground at all, so the only electrical link between them was the GPIO signal wire itself. Separating the rails and tying every ground together (battery, driver, Pi) fixed it completely, and is now a fixed rule on the car rather than a tuning choice.
A rocker switch sits in the battery line as the master on/off. We also note, as a live watch item rather than a solved problem: a freshly charged pack at 12.6 V sits marginally above the L9110S's 12 V rating, so driver temperature is worth checking after a run.

8

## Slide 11

4. Power and Sense Management

4.2 Main Components

• OV5647 wide-angle camera — a small-sensor, fixed-focus module with roughly a 120° field of view. It is the vehicle's only sensor: every wall, corner line, traffic sign and the parking gate is read from its image. Fixed focus means a large depth of field, so the near mat and a far wall stay sharp at the same time with nothing to hunt or mis-lock mid-run — a deliberate choice explained in the Evolution section.
• Raspberry Pi 4 Model B, 2 GB RAM, running Raspberry Pi OS Bookworm — the single board that captures every frame, runs the vision pipeline, decides the steering and speed, and drives the servo and motor through its GPIO header.
• L9110S dual H-bridge motor driver — a compact two-pin-per-motor interface, chosen for its small size and simple PWM control, sitting on its own supply rail straight from the battery.
• SG90 micro servo — 9 g, powered from the Pi's 5 V rail, driving the Ackermann steering linkage.

9

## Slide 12

4. Power and Sense Management

4.3 Wiring Diagram


10

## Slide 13

4. Power and Sense Management

4.4 Sensing — Vision Pipeline

• Capture: the camera is read at 640x480 in RGB888, then the frame is rotated 180° in software, since the camera is physically mounted upside-down on its mast.
• Crop and resize: only the lower portion of the frame — the mat — is kept and resized down to 320x160 before any colour work happens, which both discards background clutter above the walls and keeps every frame cheap to process.
• Median blur, then HSV: a light blur is applied first because the camera runs a short exposure and elevated gain to freeze motion, which makes the raw image noisy enough to break both the colour masks and the wall scan if left untreated. The frame is then converted to HSV, which is far more stable than RGB under the mat's own lighting variation.
• Wall detection is a two-tier test, not one brightness threshold: a pixel is a wall if it is very dark regardless of colour, OR dark and low-saturation. A single brightness cut also lit up the blue and orange corner lines and the mat's printed markings, since they are dark too — and unevenly between the two frame halves, which injected a steering bias that looked like a control problem for a long time before we traced it to the measurement itself.
• Colour lines are searched only in the bottom of the region of interest, because a line painted on the mat physically cannot appear higher in the frame than the mat itself — searching the whole frame let bluish background pixels near the top trigger false line readings.

11

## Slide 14

4. Power and Sense Management

4.4 Sensing — Camera Position

CAMERA POSITION IS CRUCIAL FOR THE ROBOT'S PERFORMANCE.

• Height 12.5 cm above the mat. The walls are 10 cm tall, so the lens must sit above the wall line to look down onto the mat and see the wall's base — the white-mat/black-wall edge, the highest-contrast feature in the frame.
• Tilt roughly 15° downward, enough to keep the mat and both wall bases in the lower frame while still seeing far enough ahead to catch a corner line or a traffic sign before reaching it.
• Centred laterally and facing dead ahead, zero yaw. Wall-following compares the left half of the frame against the right half, so any sideways offset or twist becomes a permanent steering bias that no amount of threshold tuning removes.
• Mounted on a rigid mast, not a flexible arm. A vibrating camera blurs the wall edge and injects noise straight into the steering loop, so mast stiffness is a control requirement, not a cosmetic one.
• The connection itself uses the Pi's dedicated CSI ribbon port, not a GPIO pin, so it needs no separate power and does not appear on the wiring diagram.

12

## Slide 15

5. The Robot's Evolution

5.1 Past

Two decisions from earlier in the build turned out to be wrong in ways that only showed up once we started driving, not while designing.
The first camera was a Raspberry Pi Camera Module 3 — a larger sensor with autofocus. Focused on the mat it saw the near track sharply, but distant traffic signs blurred, and blur desaturates colour badly enough that the HSV masks lost far-away signs entirely; the car only 'saw' an obstacle once it was already close. A focus sweep confirmed we genuinely could not have both near and far sharp on that sensor at once. We replaced it with the OV5647, a smaller, fixed-focus sensor with a much larger depth of field — losing autofocus cost nothing, since a ground robot never needs to refocus.
The second was the drivetrain. Our first rear axle was solid, so both driven wheels were forced to the same speed. In a corner the outer wheel has to cover more distance than the inner one, and with no way to do that it scrubbed, losing traction and sometimes stalling the car mid-turn. Our first fix was purely in software — cutting the steering limit down step by step until the scrubbing stopped, which landed near 8°. That kept the wheels turning but left the car unable to corner tightly enough to follow the track. It was a workaround for a mechanical problem, not a fix for it.

13

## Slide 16

5. The Robot's Evolution

5.2 Present

The current car fixes both of those at the source rather than around them.
A 3D-printed differential now sits on the rear axle, driven from the N20 motor through a 25:20 gear reduction. With the wheels free to turn at different speeds through a corner, the scrub is gone, and the steering limit came back up from 8° toward the linkage's mechanical ceiling.
The bigger present-day story, though, was perception rather than mechanics. Even after the camera swap, the car kept crashing near corners in both driving directions, in a way that no amount of gain or setpoint tuning changed. We eventually stripped the controller down to nothing and started saving an annotated frame every time the steering swung hard, colouring in every pixel the code was calling 'wall'. The answer was immediate: the wall detector was any dark pixel, and the blue line, the orange line, and the mat's own printed markings are all dark. They were being counted as wall — unevenly between the left and right halves of the frame — which is exactly why the fault only showed up near corners and resisted every attempt to tune it away. The controller had never been the problem; its input was lying to it.
Once the wall test was corrected to require genuine darkness or darkness plus low saturation, every distance constant in the project was re-measured from real centimetres, and the Open Challenge now completes in both directions with stable control.

14

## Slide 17

5. The Robot's Evolution

5.3 Future

• Wire the parking manoeuvre into the Obstacle Challenge's main loop. The magenta gate is detected and currently treated purely as a wall to steer around; the reserved constants for the approach and stop condition already exist in config.py, but the behaviour itself is not yet connected.
• Close out a shadow-misreading issue seen at two of the four corners in field testing, where shadow on the mat is occasionally read as part of the wall. The existing two-tier wall test already rejects most shadow; a dedicated diagnostic tool (shadow_check.py) was built to separate a genuine wall from shadow in the field, and tightening the test against this case is active work.
• Move wall-following from a pure proportional-derivative law on wall distance to a heading-plus-offset controller, so the car corrects its angle to the wall rather than only its distance from it — this should make the straights noticeably straighter.
• Track a sign's position across several frames instead of frame by frame, to smooth the approach further than the current short-memory hold already does.

15

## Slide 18

6. The Vehicle's Photos

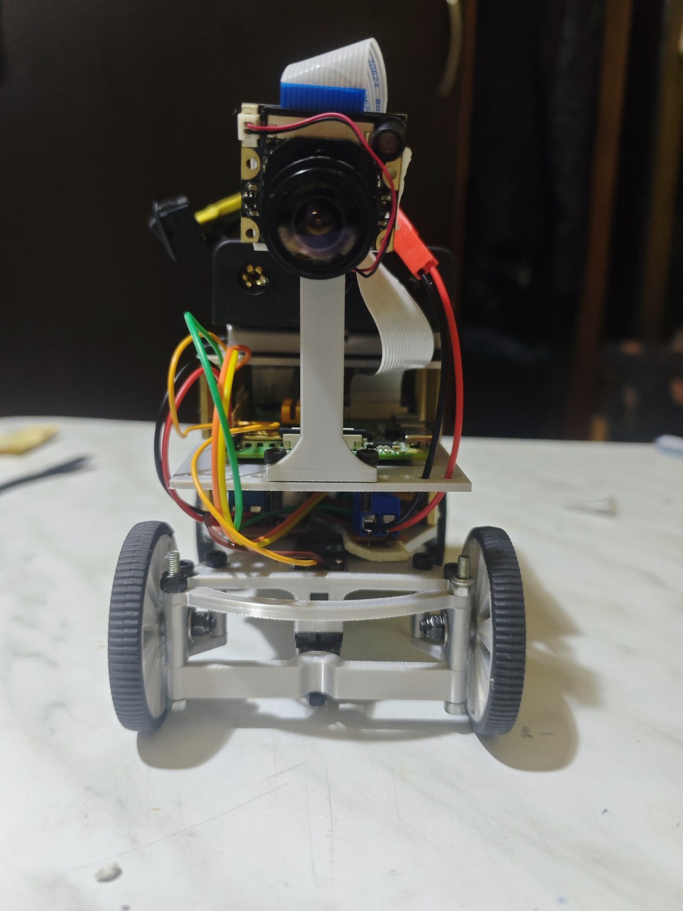
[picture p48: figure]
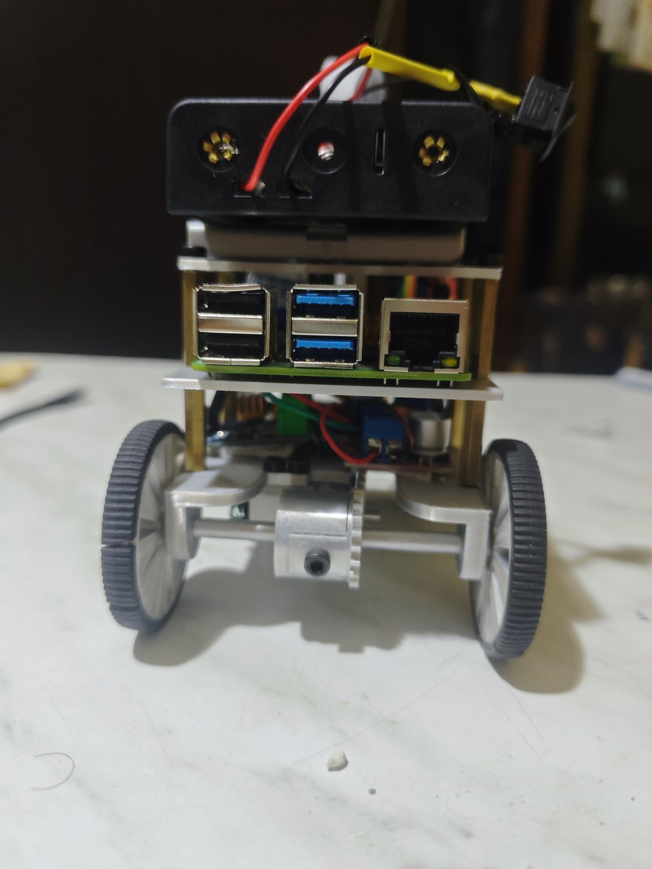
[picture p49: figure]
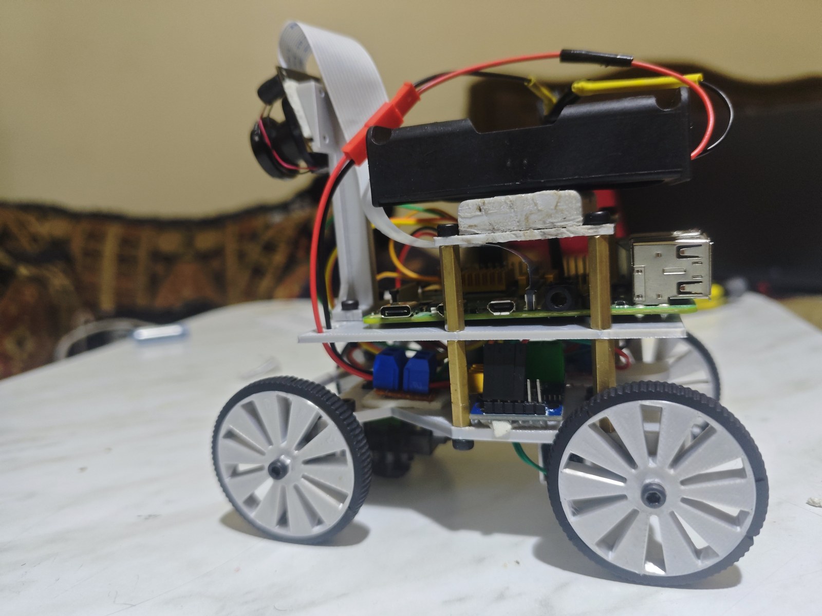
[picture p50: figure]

Left

Front

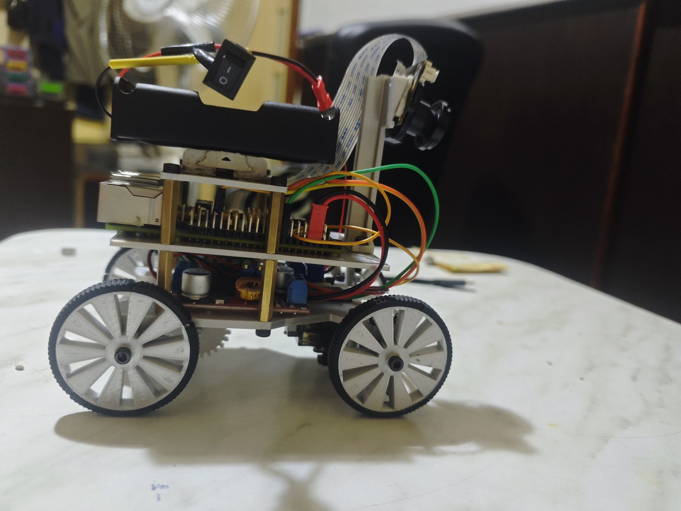
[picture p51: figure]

Right

Back

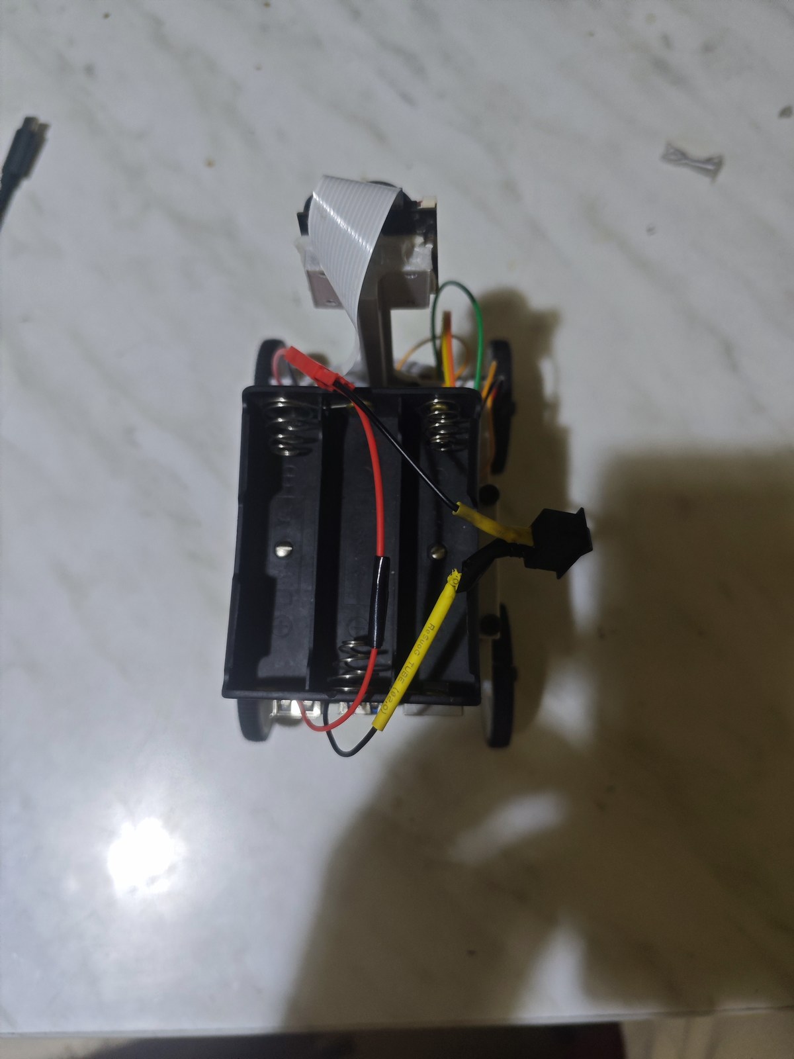
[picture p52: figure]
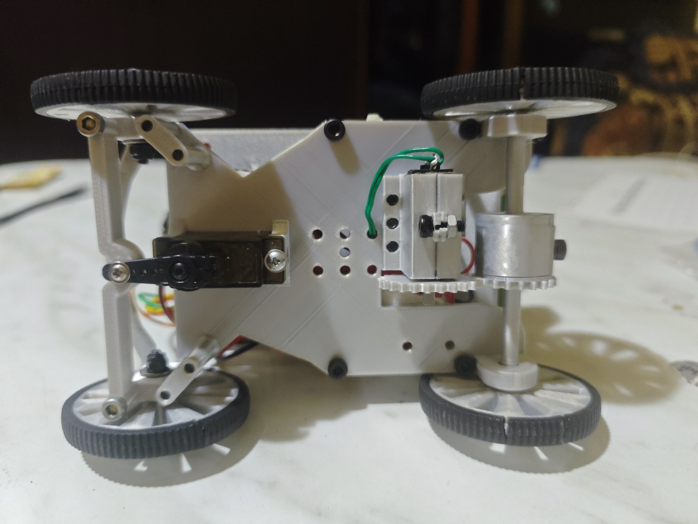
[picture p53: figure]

Bottom

Top

16

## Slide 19

7. Team


Ahmad Kalthom

Jolian Wassof

Omar Shammout

Louay Rashwan

Coach

Computer and Automation Engineering student, Damascus University.

Team member

Al-Awael School. AI, robotics and drones; WRO, Pacific and Syrian AI Olympiads.

Team member

IT Engineering student, Damascus University. Robotics, AI, electronics.

Team member

Computer and Automation Engineering student, Damascus University.

Team The Red Castle — HMK AI and Robotics Club

17

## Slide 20

8. Links and Credits

• GitHub repository (full source, CAD, documentation):
- https://github.com/jolianjij/Red-Castle-WRO-Future-Engineers-2026
• Open Challenge driving video:
- https://youtu.be/GmrX7NhcAxE
• Obstacle Challenge driving video:
- https://youtu.be/ujbImlpQH6g

Thanks

As a team, we thank HMK AI and Robotics Club for hosting and supporting us throughout this build, and our coach, Ahmad Kalthom, for the guidance that kept the project moving through every dead end along the way.

18

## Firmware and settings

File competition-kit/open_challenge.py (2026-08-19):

#!/usr/bin/env python3
"""
open_challenge.py - the team's PROVEN open-challenge program, ported to this car.

This is "openchallenge final code.py" with its LOGIC AND STRUCTURE UNCHANGED.
Same functions, same order, same control law, same constants. The only edits are
the ones this car physically forces, and every one of them is marked

    PORTED:

so you can find them all with a single search. Nothing else was touched, on
purpose: this file is a tested win and the point of the port is to keep it that
way.

Run:  cd ~/wro2026 && source .venv/bin/activate && python open_challenge.py
"""
#new variable for the open challenge surprise challenge.

#tuneables in openchallenge
blue_line_threshould = 830 #detect blue line number count of pexiles
orange_line_threshould = 930 #detect orange line number count of pexiles
speed = 100
#note in syntax if the variable is written all capital with underscore its considered constant 
LINE_BLANK_S = 1.2 # the time in second needed to wait before counting new line
#orange color in HSV after tuning.
ORANGE_SAT_MIN, ORANGE_VAL_MIN, ORANGE_VAL_MAX = 70, 30, 240
ORANGE_HUE_MIN, ORANGE_HUE_MAX = 0, 30
#blue color in HSV after tuning.
BLUE_SAT_MIN, BLUE_VAL_MIN, BLUE_VAL_MAX = 140, 20, 200
BLUE_HUE_MIN, BLUE_HUE_MAX = 90, 135
#continue driving after the 12 quadrnt 
FINISH_RUN_S = 3.0#3 seconds of drive
CW_TARGET  = 0.215      # CW follows the LEFT wall   (theirs: 0.30)
                        # NOT the raw CW measurement of 0.241 - see below.
CCW_TARGET = 0.214      # CCW follows the RIGHT wall (theirs: 0.40) MEASURED
NEUTRAL_TARGET = 0.25   # BEFORE THE DIRECTION LOCKS. Theirs was 0.5, and on
                        # OUR camera the densities only reach about 0.25 - so
                        # nothing ever exceeded it, dir stayed 0, and the car
                        # drove DEAD STRAIGHT out of the start until it found a
                        # line. Pointed even slightly inward, that is a crash
                        # into the inner wall. CCW only survived it because a
                        # line arrived at 2.7 s.
                        # Centred reads 0.215, so 0.25 does nothing until the
                        # car is genuinely close to one side.
WALL_GAIN = 75.0        # their fixed *75
#we put a limit to our servo at 20(software limit)
STEER_MAX = 20

#libraries
import cv2
import sys
import csv
import os
import shutil
# PORTED: over SSH stdout is a PIPE, and Python block-buffers pipes - so a
# run that is killed, or watched live, shows NOTHING. Line buffering makes
# the log appear cycle by cycle however the program is launched.
try:
    sys.stdout.reconfigure(line_buffering=True)
except AttributeError:
    pass
import numpy as np
from numpy.lib.stride_tricks import sliding_window_view as _swv
import time
from picamera2 import Picamera2
from libcamera import Transform            # PORTED: our camera is mounted upside down
import RPi.GPIO as GPIO
# PORTED: no NeoPixel on this car. `import board` and `import neopixel` are gone
#         and the LED functions below are no-ops, so every call site still works.

# ==========================================================================
# TUNABLES - the only numbers you should need to change
# ==========================================================================
#note from jolian those are hardware configuration.
# PORTED: our pin map (was SERVO 23, MOTOR 27/22, BUTTON 9)
SERVO_PIN = 13
MOTOR_IN1 = 24          # PWM here = FORWARD
MOTOR_IN2 = 23
BUTTON_PIN = 19
SERVO_TRIM = -9.0       # PORTED: their `angle += 0`; ours is measured at -9
STEER_DEVIATION = 35    # PORTED: their deviation was 45. OUR ACKERMANN LINKAGE
                        # STOPS AT 35 - commanding more drives the servo into
                        # its own mechanical stop, where it stalls and buzzes.

# PORTED: SMOOTHNESS. Their servo() set the angle, slept 0.1 s, then set the
# duty to ZERO - stopping the pulse train, which makes the servo go limp until
# the next command. On their slow Python loop that was once per ~0.3 s, so the
# steering was commanded, released, commanded again. That is what shakes and
# stutters.
#   SERVO_SETTLE_S  how long servo() blocks. It also CAPS THE CONTROL RATE:
#                   at 0.1 the loop cannot exceed 10 Hz no matter how fast the
#                   vision is, and slow steering on a fast car is what makes it
#                   hunt. 0.02 gives about 40 Hz.
#   SERVO_HOLD      True = keep the pulse so the servo HOLDS its angle.
#                   False = their original release-to-limp behaviour.
SERVO_SETTLE_S = 0.02
SERVO_HOLD = True

# PORTED: SHAKE. Two separate causes, two separate knobs.
#
#   SERVO_SMOOTH    The controller is a pure P term running at 34 Hz on a
#                   density signal that moves as the car does. Every cycle it
#                   hands the servo a slightly different angle, so the servo
#                   is never still. This is an exponential average on the
#                   COMMAND: 1.0 is their original raw behaviour, lower is
#                   smoother. 0.35 gives a time constant of about 85 ms -
#                   far quicker than the car turns, so it costs no response.
#
#   SERVO_DEADBAND  RPi.GPIO drives this pin with SOFTWARE PWM, and every
#                   ChangeDutyCycle call re-times the pulse train, which the
#                   servo feels as a twitch. Below this many degrees of change
#                   the duty is simply not rewritten, so a car already going
#                   straight stops being nudged 34 times a second.
#                   Set to 0.0 to write every cycle like theirs did.
SERVO_SMOOTH = 0.35
SERVO_DEADBAND = 0.8

# PORTED: WHAT THE SHAKE ACTUALLY WAS.
# RPi.GPIO generates PWM in SOFTWARE, from a Python thread. Every scheduling
# hiccup moves the pulse edge, and on a 1.5 ms servo pulse 100 us of jitter is
# about 9 degrees of commanded position - so the servo hunts no matter how
# smooth the commands are. GPIO13 is a hardware PWM pin and pigpio times the
# pulse by DMA instead.
#
# TESTED with tools/servo_jitter.py, holding ONE CONSTANT ANGLE three ways:
#     RPi.GPIO, pulse held      -> audible buzzing
#     RPi.GPIO, pulse released  -> audible buzzing
#     pigpio, DMA-timed         -> SILENT
# The command never changed inside a phase, so this was never the control loop.
#
# pigpio needs its daemon:  sudo systemctl enable --now pigpiod
# If the daemon is not running this falls back to RPi.GPIO automatically and
# says so at startup - it will drive, it will just buzz again.
SERVO_BACKEND = "pigpio"        # "pigpio" or "rpigpio" for their original


# PORTED: our camera is fixed and mounted UPSIDE DOWN, so it is flipped in
# hardware and its exposure/white balance are LOCKED. Auto anything makes the
# colour thresholds below drift under the car while it drives.
CAM_FLIP_180 = True
CAM_EXPOSURE_US = 12000
CAM_GAIN = 8.0
CAM_COLOUR_GAINS = (1.329, 1.446)
CAM_SATURATION = 1.3
CAM_CONTRAST = 1.1

# PORTED: their frame builder rotated the crop 180 degrees in software, because
# their camera was not flipped in hardware. OURS IS, so rotating again would
# swap left and right and the car would steer into the wall it is avoiding.
# If it ever does exactly that, this is the one line to flip.
ROTATE_180 = False

# PORTED: how far down the raw frame the crop starts. Theirs was 240 (the
# bottom half). Ours needs 160 - see process_frame for the measurement.
CROP_TOP = 160


# PORTED: line thresholds are PIXEL COUNTS and belong to the camera AND THE
# CROP that measured them. Re-measure with tools/line_audit.py.
#
# BLUE was SILENT on a line filling the view. MEASURED: 1077 px against their
# threshold of 1100, and 1059-1104 across 12 frames - the threshold sat INSIDE
# the frame-to-frame spread, so the same crossing flickered on and off and
# would have been counted more than once.
#
# The cause is our CROP, not the colour. CROP_TOP had to move from their 240 to
# 160 to get the walls in frame at all, which squashes 320 rows into 120 instead
# of 240 into 120. A line is mostly HORIZONTAL, so it loses pixels in direct
# proportion: the same frame gives 1421 px through their crop and 1077 through
# ours - 76%, against the 75% the geometry predicts.
#
# Their threshold fired at 1100/1421 = 77% of a full line. Keeping that same
# design ratio on our crop gives 1077 * 0.774 = 834. Bare mat reads 3-9 px, so
# there is no false-positive risk anywhere near this number.
#
# NOT changed, deliberately: BLUE_SAT_MIN. 9556 px pass every other bound and
# fail only S>140 - that is the MAT, whose hue sits inside the blue range.
# Saturation is the only thing keeping it out. Lowering it re-admits the mat.
# The hue floor of 90 does cost 580 real line pixels (the blurred edges), and
# lowering it to 88 would recover some - but green pillars measure H81-86, and
# obstacle_challenge shares this range, so it is not worth the collision.
# PORTED: BLUE'S BRIGHTNESS FLOOR, for the same reason as orange's below.
# MEASURED with the blue line in view: it is a clear 1520 px 307x36 band at
# S~223 - but its V median is 43 and its p95 only 79, against their floor of
# 70. Most of the line failed on brightness. Saturation was never the problem
# for blue; S>140 is what keeps the MAT out (the mat sits at S~71 even when its
# hue drifts into the blue range), and V was doing nothing but rejecting the
# line itself.
#     BLUE_VAL_MIN 70 -> 20
#
# PORTED: ORANGE'S BRIGHTNESS FLOOR. Theirs demanded V > 125. MEASURED on our
# field, the orange line is a clear 1648 px 320x19 band at S~178 - but its
# V median is 78 and its p95 only 106, because our whole frame tops out at
# V=143 where theirs was brighter. Their floor made orange UNREACHABLE, so the
# direction could never lock CW and every run fell to blue and went CCW.
# Hue alone separates orange from the mat here anyway - orange H~13 against the
# mat's H~70 - so the brightness floor was never doing the work.
# PORTED: ORANGE WAS SILENT TOO, and worse than blue - it never reached its
# threshold at all. MEASURED on a line filling the view: 1161-1246 across 12
# frames against a threshold of 1300. Never fires.
# Same cause, same fix: their 1300 came from their crop, which gives 1389 px on
# the very same frame our crop reads 1161 from - we keep 84%. Applying the same
# 77%-of-a-full-line rule blue got: 1199 * 0.774 = 928, so 930.
# Bare mat reads 0-87 px orange, so the margin below is about 13x.
#
# NOT changed, deliberately:
#   ORANGE_VAL_MIN stays at 30 although 444 px pass every other bound and fail
#   only it. Those are the line's shadowed edges and recovering them would
#   widen the margin - but shadow is grey, its hue is unstable at low
#   saturation, and S>70 is weak protection against it. The margin is already
#   1.25x; buying more of it with a bound that lets shadow in is a bad trade.
#   ORANGE_HUE_MAX stays at 30. The 13639 px it rejects are the MAT, not line.
#
# WHY CW_TARGET IS 0.215 AND NOT THE 0.241 THAT WAS MEASURED.
# Both directions follow the OUTER wall: clockwise the car turns right, so the
# inside of the loop is on its right and the LEFT wall is the outer one;
# counter-clockwise is the mirror. A centred car must therefore read the SAME
# density whichever way it points, and its own two halves must be nearly equal.
#
#     CCW placement:  left 0.2184   right 0.2138   gap 0.005   <- self-consistent
#     CW  placement:  left 0.2415   right 0.1825   gap 0.059   <- NOT centred
#
# The CCW reading checks out against itself; the CW one does not. The car was
# sitting nearer the left wall when CW was measured, so 0.241 encodes an
# off-centre position - it asks the car to hold 13% closer to the outer wall
# than the middle. Taking the trustworthy reading for both gives 0.215.
# Re-measure with tools/wall_calib.py if you want it confirmed: a properly
# centred CW placement should read left and right within about 0.01 of each
# other, like the CCW one does.

# NOTE these are STATIC readings at one distance. During a run the car drives
# over the line and the count PEAKS higher than this. open_log.csv records
# blue_px and orange_px every cycle, so after a run the real peak at each
# crossing can be read off directly - that is better evidence than any static
# measurement, including this one.
WALL_VAL_MAX = 70            # LEGACY single test, used only if shadow
                             # rejection below is turned OFF

# TURNING THIS ON CHANGES THE MEASURED DENSITIES, so CW_TARGET and CCW_TARGET
# must be re-measured with tools/wall_calib.py. The tool prints the old and new
# densities side by side so you can see how much shadow was being counted.
# Set WALL_SHADOW_REJECT = False to go straight back to the bare v < 70.
WALL_SHADOW_REJECT = True
WALL_V_HARD = 32        # below this it is wall regardless of saturation
WALL_V_SOFT = 62        # up to this it is wall ONLY if desaturated
WALL_S_MAX = 90         # coloured lines exceed this and are rejected
WALL_OPEN_K = 3         # square open - drops speckle and printed dots
WALL_MIN_RUN = 6        # a wall needs this many consecutive dark rows.
                        # RAISE IT if shadow still gets through; LOWER IT if
                        # distant walls start disappearing from the reading.


# ==========================================================================

OUTPUT = GPIO.OUT
INPUT = GPIO.IN
# --------------------------------------------------

STOP = False
mission_end_t = 0.0            # PORTED: a TIME now, not a cycle number
mission_end_not_activated = True

cycle_count = 0
direction = 0
quadrant_count = 0


# --------------------------------------------------
# Image variables

raw_frame = np.empty((480, 640, 3), dtype=np.uint8)
frame = np.empty((120, 320, 3), dtype=np.uint8)

# --------------------------------------------------
# Wall variables

left_wall = 0.0
right_wall = 0.0

# --------------------------------------------------

blue_line_pixel_count = 0
blue_line_next_allowed_t = 0.0

orange_line_pixel_count = 0
orange_line_next_allowed_t = 0.0

blue_line_detected = False
orange_line_detected = False

blue_line_state = 0
orange_line_state = 0

dir = 0.0
_dir_smooth = 0.0        # PORTED: state for SERVO_SMOOTH


# PORTED: log every cycle, so a bad run can be read afterwards instead of
# guessed at. Their open file wrote nothing.

# PORTED: the log is opened by main(), NOT at import. It used to be opened at
# module level, which meant that merely importing this file - which the tools
# and the test suite now do - TRUNCATED the previous run's log.
logfile = None
logwriter = None
_prev_t = 0.0
_t0 = 0.0


LOG_PATH = None


def _open_log():
    # PORTED: every run used to truncate open_log.csv, so the evidence from a
    # BAD run was destroyed by the next run - which is precisely backwards,
    # because a failure is the run worth keeping. Each run now writes its own
    # timestamped file under logs/ and open_log.csv is a copy of the latest.
    global logfile, logwriter, LOG_PATH
    os.makedirs("logs", exist_ok=True)
    LOG_PATH = os.path.join("logs", "open_%s.csv"
                            % time.strftime("%Y%m%d-%H%M%S"))
    logfile = open(LOG_PATH, "w", newline="")
    logwriter = csv.writer(logfile)
    logwriter.writerow(["cycle", "t_s", "dt_ms", "left_wall", "right_wall",
                        "blue_px", "blue_state", "orange_px", "orange_state",
                        "direction", "quadrant",
                        "dir_raw", "dir_clamped", "dir_servo"])


# --------------------------------------------------
def is_button_down():
    # PORTED: our button is wired to GND with the internal pull-up, so PRESSED
    # reads LOW. Theirs read HIGH. Same function, opposite sense.
    return GPIO.input(BUTTON_PIN) == 0

def _write_servo(angle):
    # PORTED: the two backends, writing the SAME pulse for the same angle.
    # Their duty ran 2.5% to 12.5% at 50 Hz, and 50 Hz means a 20 ms frame, so
    # their duty was really a pulse of 500 us to 2500 us across 0-180 degrees.
    # pigpio is given that pulse directly, so the centre and the throw are
    # identical either way and SERVO_TRIM does not change meaning.
    if _pi is not None:
        _pi.set_servo_pulsewidth(SERVO_PIN, 500.0 + (angle / 180.0) * 2000.0)
    else:
        servo_pwm.ChangeDutyCycle(2.5 + (angle / 180.0) * 10.0)

_last_angle = None
_pi = None                   # the pigpio handle, or None for RPi.GPIO
def servo(angle):
    """Adjust and set the servo angle."""

    global SERVO_PIN, _last_angle

    angle += 90
    deviation = STEER_DEVIATION      # PORTED: was 45; our linkage stops at 35
    if angle < 90 - deviation:
        angle = 90 - deviation
    if angle > 90 + deviation:
        angle = 90 + deviation
    angle += SERVO_TRIM          # PORTED: was `angle += 0`

    # PORTED: DEADBAND - do not rewrite the pulse for a change too small to
    # matter. Small changes still accumulate, so this cannot cause a permanent
    # offset: once the command has drifted SERVO_DEADBAND degrees it is written.
    if _last_angle is None or abs(angle - _last_angle) >= SERVO_DEADBAND:
        _write_servo(angle)
        _last_angle = angle
    time.sleep(SERVO_SETTLE_S)          # PORTED: was 0.1 - see SERVO_SETTLE_S
    if not SERVO_HOLD:                  # PORTED: theirs always released here
        if _pi is not None:
            _pi.set_servo_pulsewidth(SERVO_PIN, 0)
        else:
            servo_pwm.ChangeDutyCycle(0)
        _last_angle = None


def motor(speed):  # Speed is -1 to 1
    global MOTOR_IN1, MOTOR_IN2

    speed = max(-100, min(100, speed))
    speed_pwm = abs(speed)  # Calculate absolute speed for PWM

    if speed > 0:  # Forward

        motor1_pwm.ChangeDutyCycle(speed_pwm)
        motor2_pwm.ChangeDutyCycle(0)
    elif speed < 0:  # Reverse
        motor1_pwm.ChangeDutyCycle(0)
        motor2_pwm.ChangeDutyCycle(speed_pwm)
    else:  # Stop
        motor1_pwm.ChangeDutyCycle(0)
        motor2_pwm.ChangeDutyCycle(0)


def Setup_GPIO():
    GPIO.setmode(GPIO.BCM)
    GPIO.setwarnings(False)          # PORTED: quiet the re-run warning

    GPIO.setup(SERVO_PIN, OUTPUT)
    GPIO.setup(MOTOR_IN1, OUTPUT)
    GPIO.setup(MOTOR_IN2, OUTPUT)
    # PORTED: GPIO.setup(10, OUTPUT) was the NeoPixel data pin - not on this car
    # PORTED: the button needs the internal pull-up, being wired to GND
    GPIO.setup(BUTTON_PIN, INPUT, pull_up_down=GPIO.PUD_UP)
    global servo_pwm, motor1_pwm, motor2_pwm, _pi
    # PORTED: prefer pigpio for the servo - see SERVO_BACKEND. It is the whole
    # reason the steering stopped buzzing. Falls back to their RPi.GPIO PWM,
    # loudly, if the daemon is not up.
    servo_pwm = None
    _pi = None
    if SERVO_BACKEND == "pigpio":
        try:
            import pigpio
            _pi = pigpio.pi()
            if not _pi.connected:
                _pi = None
        except ImportError:
            _pi = None
        if _pi is None:
            print("!! pigpiod IS NOT RUNNING - falling back to RPi.GPIO software")
            print("   PWM, which is what makes the steering buzz. Fix with:")
            print("       sudo systemctl enable --now pigpiod")
    if _pi is None:
        servo_pwm = GPIO.PWM(SERVO_PIN, 50)
        servo_pwm.start(0)

    motor1_pwm = GPIO.PWM(MOTOR_IN1, 1000)
    motor2_pwm = GPIO.PWM(MOTOR_IN2, 1000)
    motor1_pwm.start(0)
    motor2_pwm.start(0)

    # PORTED: NeoPixel initialisation removed


def Setup_Camera():
    global picam2
    picam2 = Picamera2()
    # PORTED: flipped in hardware, and exposure/white balance LOCKED. Their
    # camera needed neither; ours is mounted upside down and drifts if left
    # on auto, which moves every colour threshold in this file.
    tf = Transform(hflip=1, vflip=1) if CAM_FLIP_180 else Transform()
    config = picam2.create_preview_configuration(
        main={"format": 'RGB888', "size": (640, 480)}, transform=tf)
    picam2.configure(config)
    picam2.start()
    picam2.set_controls({
        "AeEnable": False, "ExposureTime": CAM_EXPOSURE_US,
        "AnalogueGain": CAM_GAIN,
        "AwbEnable": False, "ColourGains": CAM_COLOUR_GAINS,
        "Saturation": CAM_SATURATION, "Contrast": CAM_CONTRAST,
    })
    time.sleep(1)
    return picam2


def capture_array(picam2):
    raw_frame_arr = picam2.capture_array()
    return raw_frame_arr


def process_frame(raw_frame_arr, frame_arr):
    # PORTED: identical result to their per-pixel loop, done with numpy.
    #
    # THE CROP HAD TO MOVE. Theirs took rows 240-480 - the bottom half - and on
    # their camera that half contained the walls. Ours is a 120 degree lens at
    # 12.5 cm, so the bottom half is almost entirely FLOOR: measured on the
    # field, their crop read left_wall 0.024 against their own target of 0.30,
    # and no gain can steer from a signal that is not there. Starting at
    # CROP_TOP puts the walls back in frame - the same scene then reads 0.15,
    # which is the range their constants were written for.
    crop = raw_frame_arr[CROP_TOP:480, 0:640:2]
    crop = cv2.resize(crop, (320, 120), interpolation=cv2.INTER_AREA)
    if ROTATE_180:
        crop = crop[::-1, ::-1]
    frame_arr[:] = crop
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

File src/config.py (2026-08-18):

#!/usr/bin/env python3
"""
config.py - EVERY tunable number for the car, in one place.

At the competition you should only ever need to edit THIS file (plus the
generated colors.json / servo_center.txt / camera_settings.json).
Nothing here imports anything, so it is safe to edit under pressure.

Sign conventions used everywhere:
    steering : 0 = straight, POSITIVE = RIGHT, NEGATIVE = LEFT
    speed    : -100..100, positive = forward
    direction: +1 = clockwise (turns right), -1 = counter-clockwise (turns left)
"""

# ==========================================================================
# HARDWARE PINS (BCM)
# ==========================================================================
SERVO_PIN = 13          # steering servo
MOTOR_IN1 = 24          # L9110S A-IA : PWM here = FORWARD
MOTOR_IN2 = 23          # L9110S A-IB : PWM here = REVERSE
SERVO_HZ = 50
MOTOR_HZ = 1000

# ---- START / STOP BUTTON -------------------------------------------------
# One push button does both jobs, exactly as the rules expect: the car sits
# still until you press it, and a second press stops it (the emergency stop).
#
# WIRING (the default, and the one that needs no extra parts):
#     one leg -> GPIO19,  other leg -> any GND pin
# The Pi's INTERNAL pull-up holds the pin HIGH, and pressing pulls it to GND,
# so PRESSED = LOW. That is what BUTTON_PULL_UP = True means.
# If instead you wired the button to 3V3, set BUTTON_PULL_UP = False.
# Not sure? Run:  python tools/button_test.py   - it tells you which you have.
BUTTON_PIN = 19
BUTTON_PULL_UP = True    # True = wired to GND (pressed reads LOW)
BUTTON_DEBOUNCE_S = 0.05 # ignore contact bounce for this long after any change
BUTTON_HOLDOFF_S = 0.8   # after the start press, ignore the button this long,
                         # so releasing the start press cannot read as a stop
BUTTON_REQUIRED = True   # False = fall back to pressing Enter (bench testing
                         # without the button wired up)

STOP_FLIP_DELAY = 0.3   # s to coast before reversing (protects the regulator)
STEER_MAX = 20          # deg - SOFTWARE steering limit actually used when driving.
                        # The Ackermann linkage reaches 35 deg mechanically, but the
                        # car is run at 20 for stability at full speed.
STEER_MECH_MAX = 35     # deg - the ACKERMANN LINKAGE's real mechanical limit. Only
                        # deliberate manoeuvres that ask for it (the corner kick)
                        # may go past STEER_MAX, and never past this.
SERVO_MIN_DUTY = 2.5    # duty at 0 deg
SERVO_MAX_DUTY = 12.5   # duty at 180 deg

# DRIFT TRIM - added to every DRIVING steering command (not to servo() itself,
# so centring the wheels at shutdown still centres them).
#   NEGATIVE = push LEFT      POSITIVE = push RIGHT
# MEASURED: across four runs the car always sat closer to the RIGHT wall
# (right density 0.094/0.027/0.062/0.162 vs left 0.027/0.017/0.023/0.018) even
# though the controller was already commanding LEFT on average. Steering
# direction and centre were verified correct by hand, so this is a residual
# mechanical/alignment pull. Make it MORE negative if it still drifts right,
# less negative (toward 0) if it now hugs the left wall.
STEER_BIAS = -4.0

# ==========================================================================
# SPEEDS
# ==========================================================================
CRUISE_OPEN = 100       # base speed, Open Challenge (%)
CRUISE_OBSTACLE = 100   # base speed, Obstacle Challenge (%)
SPEED_CORNER_CUT = 0.5  # how much to slow at full steering (0.5 = half speed)
MIN_SPEED = 35          # never command less than this while driving (%)

# ==========================================================================
# IMAGE / ROI
# ==========================================================================
CAM_W, CAM_H = 640, 480 # camera output
ROI_TOP = 160           # rows above this are background clutter -> ignored
PROC_W, PROC_H = 320, 160   # processing buffer size
BLUR_KSIZE = 5          # median blur before HSV (0/1 = off) - kills sensor noise
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

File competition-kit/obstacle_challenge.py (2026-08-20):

#!/usr/bin/env python3
"""
obstacle_challenge.py - the team's PROVEN obstacle program, ported to this car.

This is "promad obstacle.py" with its LOGIC AND STRUCTURE UNCHANGED. Same
functions, same order, same control law, same constants, same parking exit.
The only edits are the ones this car physically forces, and every one is marked

    PORTED:

so you can find them all with a single search.

Run:  cd ~/wro2026 && source .venv/bin/activate && python obstacle_challenge.py
"""
import cv2
import sys

# PORTED: over SSH stdout is a PIPE and Python block-buffers pipes, so a run
# that is killed or watched live shows NOTHING. Line buffering fixes that
# however the program is launched.
try:
    sys.stdout.reconfigure(line_buffering=True)
except AttributeError:
    pass
import numpy as np
import time
from picamera2 import Picamera2
from libcamera import Transform            # PORTED: our camera is upside down
import RPi.GPIO as GPIO
from array import array
import csv
import os
import shutil
from numpy.lib.stride_tricks import sliding_window_view as _swv
# PORTED: `import board` / `import neopixel` removed - no LED on this car.

#two new var
# replaced by the single sign_seen_t - see SIGN_DECAY_S
#parking out
purple_left=0.0
purple_right=0.0
Zaid=False

# ==========================================================================
# TUNABLES - the only numbers you should need to change
# ==========================================================================
# PORTED: our pin map (was SERVO 23, MOTOR 27/22, BUTTON 9)
SERVO_PIN = 13
MOTOR_IN1 = 24          # PWM here = FORWARD
MOTOR_IN2 = 23
BUTTON_PIN = 19

# PORTED: their servo centred on 105 with a deviation of 50. OUR ACKERMANN
# LINKAGE STOPS AT 35 DEGREES - commanding more drives the servo into its own
# mechanical stop and it stalls there, drawing current and buzzing. Centre is
# 90 plus our measured trim.
SERVO_CENTER = 90
SERVO_TRIM = -9.0
STEER_DEVIATION = 35

# PORTED: SMOOTHNESS. Their servo() set the angle, slept 0.1 s, then set the
# duty to ZERO - stopping the pulse train, which makes the servo go limp until
# the next command. On their slow Python loop that was once per ~0.3 s, so the
# steering was commanded, released, commanded again. That is what shakes and
# stutters.
#   SERVO_SETTLE_S  how long servo() blocks. It also CAPS THE CONTROL RATE:
#                   at 0.1 the loop cannot exceed 10 Hz no matter how fast the
#                   vision is, and slow steering on a fast car is what makes it
#                   hunt. 0.02 gives about 40 Hz.
#   SERVO_HOLD      True = keep the pulse so the servo HOLDS its angle.
#                   False = their original release-to-limp behaviour.
SERVO_SETTLE_S = 0.02
SERVO_HOLD = True

# PORTED: WHAT THE SHAKE ACTUALLY WAS - proven on this car with
# tools/servo_jitter.py, holding ONE CONSTANT ANGLE three ways:
#     RPi.GPIO, pulse held      -> buzzed
#     RPi.GPIO, pulse released  -> buzzed        (their original behaviour)
#     pigpio, DMA-timed         -> SILENT
# RPi.GPIO makes PWM in SOFTWARE from a Python thread, so every scheduling
# hiccup moves the pulse edge; 100 us of jitter on a 1.5 ms pulse is about 9
# degrees. No amount of command smoothing can fix that. GPIO13 is a hardware
# PWM pin and pigpio times it by DMA.
#   needs:  sudo systemctl enable --now pigpiod
# Falls back to RPi.GPIO automatically, loudly, if the daemon is down.
SERVO_BACKEND = "pigpio"
SERVO_SMOOTH = 0.35      # exponential average on the command; 1.0 = raw
SERVO_DEADBAND = 0.8     # deg - below this the pulse is not rewritten

# PORTED: THE 20 DEGREE RULE. config.py has always said STEER_MAX=20 is the
# software limit for ordinary driving and STEER_MECH_MAX=35 is the linkage's
# real stop. Their code had no such split - it clamped everything at its
# deviation - so wall following and sign following could command the full 35.
# Normal steering is clamped to STEER_MAX; the corner kick, the parking
# alignment and the final manoeuvre pass limit=STEER_DEVIATION explicitly,
# because those are the special cases the rule exists to make room for.
STEER_MAX = 30


speed=0

# PORTED: our camera is fixed, mounted UPSIDE DOWN, and must have exposure and
# white balance LOCKED - on auto they drift and move every threshold below.
CAM_FLIP_180 = True
CAM_EXPOSURE_US = 12000
CAM_GAIN = 8.0
CAM_COLOUR_GAINS = (1.329, 1.446)
CAM_SATURATION = 1.3
CAM_CONTRAST = 1.1
# PORTED: their process_frame rotated the crop 180 because their camera was not
# flipped in hardware. Ours is. Verified by correlating the column brightness
# profile against our proven pipeline: False +0.803, True -0.466.
ROTATE_180 = False

# PORTED: how far down the raw frame the crop starts. Theirs was 240 (the
# bottom half). Ours needs 160 - see process_frame for the measurement.
CROP_TOP = 160
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

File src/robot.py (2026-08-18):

#!/usr/bin/env python3
"""
robot.py - shared hardware + vision library for the WRO 2026 car.

Both open_challenge.py and obstacle_challenge.py import this so the pin map,
motor safety, camera settings and colour thresholds live in ONE place.

Runtime layout: keep robot.py, camera.py, colors.json (+ optional
servo_center.txt) all together in ~/wro2026 on the Pi.

Sign conventions (IMPORTANT):
  steering angle : 0 = straight, +right, -left   (clamped +-45)
  motor speed    : -100..100, + = forward
  wall metric    : left_wall / right_wall = fraction (0..1) of that half of the
                   ROI that is 'black' (a wall). Bigger = wall is closer.
"""
import collections
import json
import os
import time

import cv2
import numpy as np
import RPi.GPIO as GPIO

from camera import open_camera   # locked exposure / AWB / 180 flip / full FOV
from config import *             # ALL tunable numbers live in config.py

# center trim: written by servo_center.py; 0 if not calibrated yet
SERVO_CENTER_TRIM = 0.0
if os.path.exists("servo_center.txt"):
    try:
        SERVO_CENTER_TRIM = float(open("servo_center.txt").read().strip())
    except Exception:
        pass

_servo_pwm = None
_m1 = None
_m2 = None
_last_dir = 0


def setup_hardware():
    global _servo_pwm, _m1, _m2
    GPIO.setmode(GPIO.BCM)
    GPIO.setwarnings(False)
    for p in (SERVO_PIN, MOTOR_IN1, MOTOR_IN2):
        GPIO.setup(p, GPIO.OUT)
    GPIO.setup(BUTTON_PIN, GPIO.IN,
               pull_up_down=GPIO.PUD_UP if BUTTON_PULL_UP else GPIO.PUD_DOWN)
    _servo_pwm = GPIO.PWM(SERVO_PIN, SERVO_HZ); _servo_pwm.start(0)
    _m1 = GPIO.PWM(MOTOR_IN1, MOTOR_HZ); _m1.start(0)
    _m2 = GPIO.PWM(MOTOR_IN2, MOTOR_HZ); _m2.start(0)
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

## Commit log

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2026-08-11 Camera: switch to OV5647 fixed-focus wide (no AF, deep DOF); wall-follow now centers between walls
    [camera.py, robot.py]
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2026-08-12 Update camera to OV5647 fixed-focus wide and swap motor pins (IN1=GPIO24, IN2=GPIO23)
    [config.py, driver_on.py, motor_debug.py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]
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2026-08-12 Fuse wall geometry with colour lines for direction and lap counting
    - either signal can raise a corner; the time guard keeps it counted once
    - direction locked by the first signal, confirmed (or contested) by the second
    - geometry only votes on direction when |left-right| >= 0.08; measured 0.04 head-on
    to a corner was noise and produced an arbitrary guess against a correct line cue
    - run log records the fusion source per corner and a summary line
    [config.py, open_challenge.py, robot.py]
2026-08-12 Fix wall-hitting and phantom lap counts
    - wall EMERGENCY now runs in every nav mode; it was skipped entirely in gap mode,
    so 79 of 98 near-collision frames had no avoidance at all (log-confirmed)
    - lap logic per spec: direction fixed once from the BIGGER line + geometry, then
    quadrants counted only on a line crossing gated by a timer that restarts on
    each count (LAP_COUNT_LOCKOUT_S)
    - line edges use a SECONDS lockout, not cycles (10 cycles was 0.33s at 30fps)
    - lines are searched only in the bottom mat band; bluish background at rows 0-13
    was firing blue 41% of a run
    - steering gains raised: GAP_KP 26->80, WALL_KP 45->200 (max correction seen in a
    whole run was 6.9 of 35 deg availa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
    [config.py, open_challenge.py, robot.py]
2026-08-12 Add STEER_BIAS drift trim; restrict line search to mat band; speed to 100
    Measured across four runs: the car always sat closer to the RIGHT wall
    (right 0.094/0.027/0.062/0.162 vs left 0.027/0.017/0.023/0.018) while the
    controller was already commanding LEFT on average. Steering direction and centre
    verified correct by hand, so a residual mechanical pull is trimmed out in
    software at the single navigate() dispatch point.
    [config.py, open_challenge.py, robot.py]
2026-08-12 Raise safety timeout to 150s so a full 3-lap run can complete; fix PWM cleanup errors on exit
    [open_challenge.py, robot.py]
2026-08-12 Fix orange mask range; stop after quadrant 11; enter corners earlier
    orange [0,30,60,255,145,255] -> [8,25,45,255,70,255]
    H 8-25 clears red (which wraps 170->10 and so owned 0-10)
    S floor 60->45 and V floor 145->70: measured scene peaks at S=109 with the mat
    at V~204, so the old floors could exclude a mid-tone painted line entirely
    verified: no false trigger on bare mat (0.0000 vs 0.020 threshold)
    [config.py, open_challenge.py, robot.py]
2026-08-12 Fix white balance and separate red/orange from measured pixel values
    Root cause of the colour problems was the WHITE BALANCE, not the thresholds:
    ColourGains (1.6,1.6) gave a heavy magenta cast - 47053 of 51200 pixels read as
    saturated, nearly all at hue 135-179, so no orange existed in the image at all.
    AWB-calibrated to (1.329,1.446): bright-pixel channel spread now 5.3, saturated
    pixels 47053 -> 3572.
    With an honest image the two objects measure cleanly:
    red pillar hue~178 S~252
    orange line hue~5-8 S~90
    so they are separated on saturation as well as hue:
    red [170,5,150,255,60,255] needs S>=150
    orange [3,22,50,165,70,255] capped at S<=165
    Verified: orange 238 px, red 3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
    [robot.py]
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2026-08-12 Fix emergency steering cancelling when both walls are close; keep drift trim off corners
    Log showed L=0.993 R=0.993 producing only -4 deg: the left and right escape
    pushes summed to zero, so a car jammed facing a corner had no escape at all.
    Now commits full lock toward the open side (or the locked drive direction).
    Also: STEER_BIAS is a straight-line trim only. Applying it to corner turns cut a
    CW corner from +35 to +31 while CCW clamped harmlessly at -35, so it weakened
    cornering in one direction only.
    [robot.py]
2026-08-12 Add outer-wall PD + line-triggered scripted turn as NAV_METHOD=outer
    The approach used by the strongest camera-only teams (KyivRoboMagic 2024
    international final; Maverick 2025). Replaces three interacting controllers with
    two: one PD on the distance to the OUTER wall (the inner walls are randomised
    each round, so centring chases a moving reference), and a scripted 90 deg turn
    triggered by CROSSING THE LINE rather than by a tuned front-wall fraction.
    Deletes reliance on GAP_OPEN_FRAC / GAP_MIN_WIDTH / FRONT_ENTER / FRONT_EXIT.
    Old methods stay selectable via NAV_METHOD, so this is fully reversible.
    tools/outer_test.py validates the law with the motor untouched.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
    [config.py, open_challenge.py, outer_test.py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]
2026-08-12 Add geometry backup trigger so a missed corner line cannot cause a crash
    Line-triggered turning introduced a worse failure mode than the geometry-based
    corner detection it replaced: miss one line and the car drives straight into the
    wall. A front-wall fill above FRONT_TURN_BACKUP (0.45, deliberately above
    FRONT_ENTER) now forces the turn regardless, so the line stays the primary and
    accurate cue while geometry is the fallback - the inverse of the old design.
    [config.py, open_challenge.py, robot.py]
2026-08-12 Correct outer-wall gain from the real KyivRoboMagic source; archive their code as reference
    Read their actual .cpp instead of a summary. Two corrections:
    1. The open challenge has NO emergency override - the 0.625 threshold I had cited
    is in the obstacle file only. Their entire open-challenge steering is the
    outer-wall law plus nothing.
    2. Scaling was wrong. Their half-image is 19200 px but they divide by 12800, so
    their value maxes at 1.5 and the 0.5 setpoint is really 33% dark. Correct
    equivalent gain on our +-20 clamp is 50, not 160 - we were running over 3x
    their aggressiveness, saturating at err 0.125 vs their 0.4.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
    [config.py]
2026-08-12 Calibrate outer-wall controller from measured density-vs-distance
    Measured on the field, car parallel to the outer wall:
    29 cm -> 0.2044 19 cm -> 0.2619 slope 0.00575 density/cm
    OUTER_TARGET 0.14 -> 0.204 (the density at the 29 cm driving line; 0.14 was a
    guess from old logs and had the car aiming much further out than intended).
    OUTER_KP restored to 160. Scaling their gain of 75 by control-shape gave 50, but
    that assumed our density responds to distance as theirs did - it does not. At
    KP=50 a 10 cm error produces 2.9 deg and full lock needs 70 cm, wider than the
    corridor. At KP=160 a 10 cm error gives 9.2 deg and full lock at 21.7 cm.
    Calibrated response: 39cm -> -11.7, 29c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
    [config.py]
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2026-08-12 Fix NameError in navigate(); geometry-terminated turn; emergency flees the closer wall
    - navigate() referenced 'front' which was not a parameter (only front_close was),
    crashing the run on the first frame. Added front and a fallback.
    - turn now exits when the corner is CLEAR (front < FRONT_EXIT) with TURN_MIN_S /
    TURN_DURATION_S as floor and cap. The fixed 1.1s hold over-rotated into the
    INNER wall in both directions (inner density climbed 0.126->0.195->0.278 during
    the turn), which is why it crashed mid-second-section in CW and CCW alike.
    - emergency-both now steers away from the CLOSER wall. It used the drive
    direction, so jammed against the inner wall in CCW it steered LEFT into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
    [config.py, dryrun.py, open_challenge.py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]
2026-08-12 Emergency override was WEAKER than the controller it replaced - the cause of the wall crashes
    Log (t=1.05s, right=0.285, just past the 0.28 threshold):
    mode=emergency steer=-0.8
    while the outer-wall controller at that same instant wanted -17. The emergency
    ramped from ZERO, so on crossing the threshold it seized control and commanded
    almost nothing - the car kept driving into the wall while nominally escaping it.
    Right climbed 0.089 -> 0.156 -> 0.285 -> 0.414 through this.
    Now: ramps from HALF lock to full across the danger band, and is floored by the
    normal command so it can never steer less than the controller it overrides.
    right=0.285 -> -16.6 deg (was -0.8)
    Also latch the esca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
    [robot.py]
2026-08-12 Stop counting the BLUE/ORANGE lines and mat markings as walls
    Diagnostic frames from a failed run show the wall mask (value < 62) covering the
    blue corner line, the orange corner line and the mat's printed dotted markings.
    They were counted as walls on every frame, and unevenly between halves, so they
    injected a steering bias exactly when lines came into view - at the corners.
    Measured on a failure frame: left 0.164 -> 0.072, right 0.256 -> 0.172.
    New rule (wall_mask): very dark OR (dark AND desaturated), then a morphological
    open to drop the dots. Both cases are needed - HSV saturation is meaningless at
    very low brightness, so a saturation test alone rejected 99% of a nose-to-wall
    frame, w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
    [config.py, pure_open.py, robot.py]
2026-08-12 Re-calibrate all wall constants against the corrected mask
    Measured car-side to wall-face, parallel, on a straight:
    40 cm -> 0.1032 25 cm -> 0.1783 slope 0.00501 density/cm
    All previous numbers came from the mask that counted the coloured lines as walls
    and are void.
    OUTER_TARGET 0.204 -> 0.1032 the 40 cm driving line (centred is ~45 cm).
    0.204 meant driving at 29 cm with the panic
    threshold at ~16 cm: only 13 cm of margin, which
    is why emergency fired constantly.
    WALL_EMERGENCY 0.28 -> 0.213 ~18 cm, leaving 22 cm of margin.
    OUTER_KP 160 -> 200 5 cm off -> 5 deg,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
    [config.py]
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2026-08-12 Rewrite Obstacle Challenge to KyivRoboMagic's actual structure; magenta counts as wall
    Read from their obstacle_challenge_3.cpp rather than a summary. Their control
    block is, in order:
    dir = Err * kp sign steering is the PRIMARY control
    if outer wall too close: dir = +-45 wall override (this also turns corners)
    There is NO wall following: with no sign in view Err = 0 and the car drives
    straight. Reproduced exactly.
    Their sign law, verbatim:
    green: Err = -((180 + y*2) - x) push the sign to the RIGHT of frame
    red : Err = (x - (140 - y*2)) push the sign to the LEFT of frame
    so green is passed on the left and red on the right, with the target c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
    [config.py, obstacle_challenge.py, robot.py]
2026-08-12 Obstacle: restore lane keeping between signs, hold a manoeuvre through detection flicker
    First run failed with 232 of 526 frames (44%) at steer=0.0. Their design has no
    lane keeping - with no sign in view the car drives straight and relies on the wall
    override to keep it in the corridor. That works on their optics; on ours the walls
    measure L=0.112 R=0.129 against a 0.213 threshold, so the override rarely fires
    and the car simply drove into things.
    Between signs we now use the outer-wall law that scored full marks in the Open
    Challenge. Sign steering remains primary, the wall override still outranks all.
    Also added SIGN_MEMORY: detection toggled with 'straight' frame to frame
    (area 61 -> 8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
    [obstacle_challenge.py]
2026-08-12 Measure the green sign; the wall/mat boundary fringe was masking it
    Green had never been measured - it sat on KyivRoboMagic's default range and
    matched 0% of our pillar. Measuring exposed a second problem: the wall/mat
    BOUNDARY FRINGE (the chromatic edge where black wall meets white mat) reads as
    green at S96-111, and below that floor it MERGED with the pillar into one wide
    blob, which the 'taller than wide' sign filter then discarded. So green signs
    could never be detected at all.
    Saturation separates all three:
    boundary fringe S 96-111
    the mat itself S ~50
    the green pillar S 135+
    Set green to [30, 95, 140, 255, 30, 170]. At S>=140 the fringe vanishes entirely
    and the pillar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
    [robot.py]
2026-08-13 Add CAD/BOM/video links; remove all named-team references from docs and code
    - Add driving demonstration links (Open + Obstacle Challenge YouTube videos)
    - Import full mechanical CAD: 20 part STLs across 5 subassemblies (chassis,
    steering, rear-drive/differential, wheels, battery slider) plus the 5
    pre-sliced Bambu Studio 3MF print plates and the source Mechanical-BOM.docx
    - Reproduce the printed-parts BOM (20 parts, qty, fixed/moving, material) as a
    table in models/README.md, cross-linked from the main BOM
    - Remove every reference to the external team whose algorithm we studied, from
    config.py, robot.py, obstacle_challenge.py, legacy_open.py, pure_open.py and
    ENGINEERING-JOURNAL.m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
    [Camera holder.stl, N20 motor holder.stl, Ring.stl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]
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2026-08-13 Rebuild Engineering Journal with real testing photos, flowcharts, and part renders
    Adds the visual proof and diagrams the rubric asks for and the deck was
    missing: native pptx flowcharts for the control loop and Obstacle Challenge
    priority, real Pi captures proving the camera swap plus the flip/colour-
    tuning/masking/calibration process, a component-rationale table, and a
    printed-parts photo gallery filling the BOM table's placeholders.
    [build_pptx_journal.py]
2026-08-13 Fix caption/body-text overlaps found in a full pre-submission read-through
    Steering, driving-assembly, and body/3D-design slides had captions running
    into the image or text below them from the original deck build; tightened
    the vertical spacing on all three. Also removed the stale, gitignored
    Engineering-Journal.html, generated before the external-team reference was
    purged from the source docs -- it still named the reference team and had
    no reason to keep existing now that the pptx/pdf is the real deliverable.
    [build_pptx_journal.py]
2026-08-13 Correct the steering servo to MG90S (was mislabelled SG90 everywhere)
    Fixed every reference across README.md, schemes/README.md, models/README.md,
    the BOM, CHECKLIST.md, and the Engineering Journal builder. The component-
    rationale table now correctly names MG90S as the actual choice and SG90 as
    the rejected alternative -- SG90's plastic gears were the concern under
    repeated full-lock steering, not the other way around. Also pointed the
    stale "still to add: BOM photos" note in models/3d-parts/README.md at the
    part renders that already exist in models/renders/parts/.
    [build_pptx_journal.py]
2026-08-13 Consolidate the submission to a single Documentation.pdf
    Drop ENGINEERING-JOURNAL.md and Engineering-Journal.pptx from the repo --
    one clean PDF is easier for judges to review than three overlapping
    artifacts, and the .pptx's content already carries the journal's narrative
    in full. build_pptx_journal.py now writes a gitignored Documentation.pptx
    as an intermediate; only the exported Documentation.pdf is committed.
    Also removed build_journal.py, the older HTML-based generator that read
    ENGINEERING-JOURNAL.md directly and can no longer run now that the file is
    gone. Updated every cross-reference (README, CHECKLIST, BOM docs) to point
    at Documentation.pdf.
    [build_pptx_journal.py]
2026-08-14 Obstacle diagnostic build: magenta removed, tunables block, pass frames, sign-order list
    - MAGENTA_IS_WALL = False; magenta is off the track so it is ignored entirely
    - all tunables gathered in one TUNABLES block at the top of the file
    - annotated frames saved through every pass: detected sign box, its centroid, the
    target column it is being pushed toward, the wall mask and the steering
    - PassLogger builds the ORDER of signs passed, e.g. ['red','green','green'],
    printed live, summarised at the end and written to sign_order.txt
    The order algorithm was tested offline before deployment and two bugs were fixed:
    _last_t started at 0.0 so the first commit was suppressed for the first 1.5 s,
    a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
    [config.py, obstacle_challenge.py]
2026-08-14 Obstacle: 50 cm lane keeping between signs; direction auto-detected, no forcing
    LANE_DISTANCE_CM = 50 with LANE_TARGET derived from the measured calibration
    (0.1032 at 40 cm, 0.00501 per cm), so the lane setpoint is stated in centimetres
    and the density follows from it. OuterWallFollower now takes a per-instance
    target so the obstacle run can hold 50 cm while the open run holds 40 cm.
    FORCE_CW back to False. The direction now comes from the first corner line, and
    until one is seen the follower CENTRES between the two walls instead of silently
    assuming clockwise - previously direction 0 was treated as CW, which picked a
    side arbitrarily and could hug the wrong wall for the whole opening stre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
    [obstacle_challenge.py, robot.py]
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2026-08-14 Corner-exit kick, per-colour line thresholds, and a testable decision ladder
    THREE CHANGES.
    1. CORNER-EXIT KICK (robot.CornerKick, wired into the Obstacle Challenge)
    The last sign before a corner leaves the car pushed to one side. When that push
    was toward the INNER wall, the car enters the corner pointing across it: the
    next section is not in frame at all, so every closed-loop controller is reacting
    to a wall it is about to leave behind. A short, hard, OPEN-LOOP turn in the
    corner's own direction now swings the nose round until the next section is
    visible, then normal control resumes.
    Which sign arms it follows from which wall is 'inner', and that flips with
    direction:
    CW - corners t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
    [config.py, obstacle_challenge.py, open_challenge.py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]
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2026-08-17 Venue kit: headless recalibration, wired networking, boot autostart
    Four things needed at a venue that bans wireless and has different lighting.
    RECALIBRATION, HEADLESS
    tools/tune_colors.py re-locks exposure and white balance to the room, then
    walks colour by colour: fill the middle of the view with an object, press
    Enter. It samples the centre box, discards background by hue distance from the
    box median, and builds a range from percentiles. Then it checks EVERY PAIR for
    overlap - a range correct on its own is still wrong if it also matches the
    pillar beside it, which is exactly how red came to swallow magenta.
    Deliberately headless: it runs in a plain SSH terminal. At a venue the screen
    i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
    [robot.py, tune_colors.py, tune_walls.py]
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2026-08-18 Review pass: three bugs fixed, plus a generated code walkthrough
    Read the code against its own documented claims. Three of them were not true.
    BUG 1 - the car drove during the "stationary" measurement
    ParkingExit averages 8 frames specifically because the car is still, those
    being the only unblurred frames in a run. But the settle phase returned
    PARK_SPEED, so the car rolled forward at 45% throughout, defeating the entire
    justification. The live dryrun showed it in the first line of output:
    0: park-look steer=+0.0 speed=45 before
    0: park-look steer=+0.0 speed= 0 after
    update() now returns a speed alongside the steer, and the settle phase commands
    zero.
    BUG 2 - the lap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
    [build-code-walkthrough.py, dryrun.py, obstacle_challenge.py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]
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2026-08-18 Parking lot works on the track: fix the red/magenta boundary
    Ran the parking exit for the first time with the car actually in the lot. It
    made a coin-toss decision (1.40x margin), and the picture showed why.
    RED WAS CLAIMING THE PARKING WALL
    The wall's body reads H 171-177, S 165-229, V 47-85. Red's wrap started at 174,
    so the wall fell INSIDE red: the biggest "red" blob in frame was a 119x20 slab
    of parking wall. Only find_sign's taller-than-wide test was stopping it being
    treated as a traffic sign.
    MAGENTA COULD ONLY SEE THE WALL'S LIT EDGE
    The old range was tuned on the magenta block at a distance in good light
    (S~130, V~179). The same wall up close and shadowed is S~207, V~60, so it
    fa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
    [obstacle_challenge.py, park_check.py, robot.py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]
2026-08-18 Correct the black-wall rationale: on the real track the signals agree
    The recorded reason for PARK_USE_WALL=False was wrong, and the real measurement
    says so.
    A synthetic test appeared to show magenta and the black wall ANTI-correlated -
    the magenta wall occludes the black one behind it, so the blocked side shows
    less black. Measured in the actual lot they AGREE:
    magenta L 0.716 R 0.449 -> left is blocked
    wall L 0.174 R 0.093 -> names the same side
    The anti-correlation was an artifact of the synthetic image, where the blank
    background counted as wall. Corrected in the code comment, README 5.1d, and the
    field manual, which now carries it as "Corrected" rather than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
    [obstacle_challenge.py, test_logic.py]
2026-08-18 Stop the sign law steering into walls; decouple the stop duration
    DIAGNOSED FROM logs/obstacle_20260818_062223.csv - the run that failed.
    frames past WALL_EMERGENCY 628 of 1707 (37% of the run)
    right wall peak 0.582 (escape threshold 0.213)
    time in sign-related modes 58.7%
    quadrants counted in 56 s 14 (a whole race is 12)
    The saved frames show it directly. Frame 339: a green sign of area 254 detected,
    steer -20.0 (FULL left lock), while the left wall already read 0.20 against the
    0.213 threshold. The car was driving full-lock into a wall to place a sign, the
    escape fired, and the two fought each other for a third of the run.
    ROOT CAUSE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
    [obstacle_challenge.py, open_challenge.py, robot.py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]
2026-08-18 Per-colour sign tuning, color_count(), parking-aware stop, laptop<->Pi sync
    WHAT THE FAILED OBSTACLE RUN ACTUALLY SHOWS (logs/obstacle_20260818_080111)
    green 738 frames (37%) median area 186 max 8370
    red 351 frames (18%) median area 718 max 4704
    wall 801 frames (40%) final quadrant 17
    Green IS being detected and steered for - it is not ignored. But it arrives as
    much SMALLER, more broken-up blobs than red, and find_sign() gates both colours
    on one shared min area and one shared "taller than wide" test. Green fails that
    test intermittently where red does not, so green passes are the ones that come
    apart. Hence per-colour parameters, which is what was asked for.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
    [button_test.py, camera.py, camera_tune.py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]
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2026-08-18 Decisive-frame recorder, API reference, video colour tool - and a review
    REVIEW FINDINGS (four, from reading the code against what it claims)
    1. THE DIRECTION-DETERMINING CROSSING IS NOT COUNTED AS A QUADRANT, and nothing
    said so. Phase 1 sets _last_count_t = now when it locks the direction, and
    Phase 2 then computes elapsed = 0 in the SAME frame, so the crossing that
    decided the direction is silently swallowed. That is CORRECT - it is exactly
    why STOP_QUADRANT needs +1 when the parking exit supplies the direction
    instead - but it emerged from an assignment rather than being stated, and a
    later "tidy-up" would have broken the stop rule without touching it.
    Now documente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
    [build-api-reference.py, obstacle_challenge.py, open_challenge.py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]
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2026-08-18 Turns from wall density in Open; stop the guard blocking every green pass
    GREEN WAS NEVER AVOIDED, AND IT WAS MY GUARD DOING IT.
    From logs/obstacle_20260818_122952: green was detected on 45% of frames and
    steered for on 412 of them at a mean of -8.9 deg, so it was seen and acted on.
    But:
    388 frames steering LEFT for green
    226 of them (58%) had the LEFT wall past the guard's fade threshold
    when green was CLOSEST (area > 2000) the left wall averaged 0.172,
    peaking 0.210 - the fade band is 0.149 to 0.213
    A GREEN sign must be passed on its LEFT. In CW the outer wall IS on the left.
    So every green pass steers toward a wall BY GEOMETRY, not by mistake - and
    SIGN_WALL_GUARD faded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
    [obstacle_challenge.py, open_challenge.py, robot.py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]
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
